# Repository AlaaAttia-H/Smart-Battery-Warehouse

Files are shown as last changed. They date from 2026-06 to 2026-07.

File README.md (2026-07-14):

# Smart Battery Warehouse Monitoring and Response System

## Overview

This project implements a Smart Battery Warehouse Monitoring and Response System using:

```text
IoT sensing
MQTT communication
AI planning
automatic actuator control
dashboard visualisation
manager notifications
```

The system monitors:

```text
temperature
humidity
gas_status
occupancy
battery_status
```

The system controls:

```text
fan
buzzer
RGB LED
shutter/servo
manager notifications
dashboard updates
```

## Main System Structure

```text
Smart-Battery-Warehouse/
├── README.md
├── laptop/
│   ├── README.md
│   └── src/
├── raspberry-pi/
│   ├── README.md
│   └── src/
├── dashboard/
│   ├── README.md
│   └── flows.json
└── docs/component README files
```

## Where to Find Setup Instructions

This root README gives only the general overview.  
For detailed setup and running instructions, use the README file inside each component folder.

### Raspberry Pi Setup

Use:

```text
raspberry-pi/README.md
```

This explains:

```text
Raspberry Pi connection
Mosquitto setup
pigpio setup
copying Raspberry Pi files
running the hardware node
battery input
Grove button occupancy
I2C troubleshooting
manual MQTT tests
```

### Laptop Controller Setup

Use:

```text
laptop/README.md
```

This explains:

```text
Python virtual environment
MQTT broker IP configuration
running the laptop AI controller
context signature
replanning logic
```

### AI Planner Setup

Use:

```text
laptop/src/planner/README.md
```

This explains:

```text
Fast Downward download and setup
PDDL domain and problem files
problem_generator.py logic
planner testing
HIGH/MEDIUM/LOW planning rules
shutter planning based on occupancy
```

### Executor Explanation

Use:

```text
laptop/src/executor/README.md
```

This explains:

```text
how planner actions are executed
how MQTT commands are published
why the executor stays generic
```

### Knowledge Base Explanation

Use:

```text
laptop/src/knowledge_base/README.md
```

This explains:

```text
planner action to MQTT mappings
warehouse zones
notification meanings
threshold access
```

### MQTT Topics

Use:

```text
laptop/src/mqtt/README.md
```

or the MQTT README in the project docs, depending on the final folder structure.

This explains:

```text
sensor topics
context topics
planning topics
notification topics
actuator command topics
example payloads
```

### Notifications Setup

Use:

```text
laptop/src/notifications/README.md
```

This explains:

```text
ntfy setup
notification topic
notification testing
notification action meanings
```

### Dashboard Setup

Use:

```text
dashboard/README.md
```

This explains:

```text
Node-RED setup
Dashboard 2 installation
importing flows.json
dashboard MQTT topics
opening the dashboard page
```

## Main Component Responsibilities

### Raspberry Pi

```text
runs Mosquitto MQTT broker
runs the hardware node
reads DHT temperature/humidity
reads MQ2 gas status
reads Grove button occupancy
reads battery value from JSON input
controls fan, buzzer, RGB LED, and shutter/servo
runs Node-RED dashboard server
```

### Laptop

```text
receives sensor values through MQTT
calculates risk level and battery condition
generates PDDL problem files
runs Fast Downward
executes planner actions through MQTT
sends ntfy notifications
publishes dashboard context and plan topics
```

### Dashboard

```text
subscribes to MQTT topics
shows live sensor values
shows risk level and system state
shows current and previous AI plans
shows notifications and actuator states
```

## Final Behaviour Summary

### Normal

```text
risk_level = LOW
LED = GREEN
fan = OFF
buzzer = OFF
shutter = OPEN
```

### Medium Risk

```text
risk_level = MEDIUM
LED = ORANGE
fan = ON
buzzer = OFF
shutter = OPEN
```

### High Risk With Occupancy

```text
risk_level = HIGH
occupancy = 1
LED = RED
buzzer gives two short beeps
manager receives high-risk notification
evacuation notification is sent
shutter stays open
```

### High Risk Without Occupancy

```text
risk_level = HIGH
occupancy = 0
LED = RED
buzzer gives two short beeps
manager receives high-risk notification
shutter closes
```

### Battery Low

```text
battery_condition = LOW
manager receives battery warning notification
```

### Battery Critical

```text
battery_condition = CRITICAL
manager receives battery maintenance notification
```

## Full Run Order

For full detailed commands, see the component README files.

General order:

```text
1. Start Mosquitto on Raspberry Pi.
2. Start Node-RED dashboard on Raspberry Pi.
3. Start Raspberry Pi hardware node.
4. Start battery input if needed.
5. Start laptop AI controller.
6. Open dashboard.
7. Test demo scenarios.
```

## Important Notes

```text
Mosquitto broker runs on Raspberry Pi.
Raspberry Pi hardware node runs on Raspberry Pi.
Node-RED dashboard runs on Raspberry Pi.
Fast Downward runs on the laptop.
Laptop AI controller runs on the laptop.
The executor stays generic and only publishes mapped MQTT actions.
The Raspberry Pi only executes received actuator commands.
The planner/problem generator decides which actions are needed.
```

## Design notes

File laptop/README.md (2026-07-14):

# Laptop Controller Setup

This README explains how to set up and run the laptop side of the project.

The laptop runs:

```text
MQTT laptop controller
context processor
PDDL problem generator
Fast Downward planner
plan executor
notification manager
```

## 1. Open the Project Folder

Open the project root in VS Code or PowerShell:

```powershell
cd "<PATH_TO_PROJECT>/Smart-Battery-Warehouse"
```

Example:

```powershell
cd "C:\Users\<YOUR_USERNAME>\Documents\Smart-Battery-Warehouse"
```

## 2. Create Virtual Environment

```powershell
python -m venv venv
```

Activate it:

```powershell
.\venv\Scripts\activate
```

## 3. Install Required Packages

```powershell
python -m pip install --upgrade pip
python -m pip install paho-mqtt requests
```

## 4. Configure Raspberry Pi Broker IP

Edit:

```text
config/config.json
```

Set the Raspberry Pi IP:

```json
"mqtt": {
  "broker_host": "<RASPBERRY_PI_IP>",
  "broker_port": 1883
}
```

Example:

```json
"mqtt": {
  "broker_host": "192.168.137.70",
  "broker_port": 1883
}
```

## 5. Run the Laptop Controller

From the project root:

```powershell
.\venv\Scripts\activate
python laptop/src/main.py
```

The controller will:

```text
subscribe to sensor topics
calculate risk level and battery condition
publish context topics
generate PDDL problem
run planner
publish current and last plans
execute MQTT actuator commands
send notifications
```

## 6. Important

Run the controller from the project root.

Use:

```powershell
python laptop/src/main.py
```

Do not run package files directly like:

```powershell
python mqtt/laptop_controller.py
```

because that can cause import errors.

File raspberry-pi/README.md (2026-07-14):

# Raspberry Pi Setup and Run Guide

This README explains the Raspberry Pi side of the Smart Battery Warehouse project.

The Raspberry Pi is responsible for:

```text
running the Mosquitto MQTT broker
running the Raspberry Pi hardware node
publishing sensor values
reading the Grove button for occupancy
reading battery status from a JSON input file
receiving actuator commands
controlling the fan, buzzer, RGB LED, and shutter/servo
running the Node-RED dashboard server
```

## 1. Hardware and Pi Information

```text
Model: Raspberry Pi Model B+
OS: Raspberry Pi OS Lite 32-bit
Hostname: SCIOT
Username: group29
Password: SCIOT29-group
```

## 2. Project Structure on the Raspberry Pi

The code should be copied to:

```text
/home/group29/sciot_project/
```

Expected structure:

```text
sciot_project/
├── main.py
├── battery_simulator.py
├── runtime/
│   └── battery_state.json
├── hardware/
│   ├── grove_inputs.py
│   ├── grove_outputs.py
│   └── pi_direct.py
└── mqtt/
    ├── rpi_hardware_node.py
    └── topics.py
```

## 3. Connect to the Raspberry Pi

From Windows PowerShell:

```powershell
ssh group29@SCIOT.local
```

or:

```powershell
ssh group29@<RASPBERRY_PI_IP>
```

To check the Raspberry Pi IP after logging in:

```bash
hostname -I
```

## 4. Install and Start Mosquitto

Mosquitto is the MQTT broker. It runs on the Raspberry Pi.

Check if Mosquitto is running:

sudo systemctl status mosquitto

Start Mosquitto:

```bash
sudo systemctl start mosquitto
```

Enable Mosquitto on boot:

```bash
sudo systemctl enable mosquitto
```

Check status:

```bash
sudo systemctl status mosquitto
```

Check that port `1883` is open:

```bash
sudo ss -ltnp | grep 1883
```
Install Mosquitto if needed:

```bash
sudo apt update
sudo apt install mosquitto mosquitto-clients -y
```

## 5. Allow Laptop Connections to Mosquitto

If the laptop controller cannot connect to the broker, create or edit:

```bash
sudo nano /etc/mosquitto/conf.d/sciot.conf
```

Add:

```text
listener 1883
allow_anonymous true
```

Restart Mosquitto:

```bash
sudo systemctl restart mosquitto
```

## 6. Create Project Folder on Raspberry Pi

```bash
mkdir -p ~/sciot_project
mkdir -p ~/sciot_project/mqtt
mkdir -p ~/sciot_project/hardware
mkdir -p ~/sciot_project/runtime
```

## 7. Create and Activate Virtual Environment

```bash
cd ~/sciot_project
python3 -m venv venv
source venv/bin/activate
```

Install required Python packages:

```bash
pip install paho-mqtt
```

If needed, also install the hardware libraries used by the Pi code:

```bash
pip install smbus2 pigpio
```

## 8. Enable pigpio

The servo, MQ2 sensor, and RGB LED use direct Raspberry Pi GPIO through `pigpio`.

Check status:

```bash
sudo systemctl status pigpiod
```

Start pigpio:

```bash
sudo systemctl start pigpiod
```

Enable on boot:

```bash
sudo systemctl enable pigpiod
```

## 9. Copy Raspberry Pi Code from Laptop to Pi

From Windows PowerShell, run these commands from the main project root:

```powershell
scp -r .\raspberry-pi\src\ group29@<RASPBERRY_PI_IP>:/home/group29/sciot_project/
```

Example:

```powershell
scp .\raspberry-pi\src\main.py group29@192.168.137.70:/home/group29/sciot_project/main.py
```

## 10. Run the Raspberry Pi Hardware Node

On the Raspberry Pi:

```bash
cd ~/sciot_project
source venv/bin/activate
python main.py
```

The hardware node publishes:

```text
warehouse/sensors/temperature
warehouse/sensors/humidity
warehouse/sensors/gas_status
warehouse/sensors/occupancy
warehouse/sensors/battery_status
```

The hardware node subscribes to:

```text
warehouse/actuators/fan/command
warehouse/actuators/buzzer/command
warehouse/actuators/led/command
warehouse/actuators/shutter/command
```

## 11. Run Battery Input

Battery status is entered manually because the project does not use a real battery sensor.

Open another Raspberry Pi terminal:

```bash
cd ~/sciot_project
source venv/bin/activate
python battery_input.py
```

Example values:

```text
90 -> normal battery
40 -> low battery
10 -> critical battery
```

The value is written to:

```text
runtime/battery_state.json
```

The Raspberry Pi hardware node reads this file and publishes the value to:

```text
warehouse/sensors/battery_status
```

## 12. Occupancy Input

Occupancy is controlled using the real Grove button.

```text
button press toggles occupancy between 0 and 1
```

The Raspberry Pi publishes the current occupancy to:

```text
warehouse/sensors/occupancy
```

There is no separate `occupancy_input.py` script in the final hardware version because occupancy comes from the real button.

## 13. Hardware Behaviour

### DHT Sensor

The DHT sensor provides:

```text
temperature
humidity
```

These are published to:

```text
warehouse/sensors/temperature
warehouse/sensors/humidity
```

### MQ2 Gas Sensor

The MQ2 sensor publishes:

```text
OK
ALERT
```

to:

```text
warehouse/sensors/gas_status
```

### Fan

The fan receives MQTT commands on:

```text
warehouse/actuators/fan/command
```

Example payloads:

```text
OFF
ON
40
70
```

### Buzzer

The buzzer receives commands on:

```text
warehouse/actuators/buzzer/command
```

For an `ON` command, the buzzer gives two short beeps and then turns off automatically.

### RGB LED

The RGB LED receives commands on:

```text
warehouse/actuators/led/command
```

Example payloads:

```text
GREEN
ORANGE
RED
OFF
```

### Shutter / Servo

The shutter servo receives commands on:

```text
warehouse/actuators/shutter/command
```

Example payloads:

```text
OPEN
CLOSE
HALF
```

The Raspberry Pi only executes the command it receives. The decision about whether the shutter should close is made by the laptop AI planner/problem generator.

## 14. Start Node-RED Dashboard

Node-RED runs on the Raspberry Pi.

Start Node-RED:

```bash
node-red-start
```

Open the Node-RED editor from the laptop browser:

```text
http://<RASPBERRY_PI_IP>:1880
```

Open the dashboard:

```text
http://<RASPBERRY_PI_IP>:1880/dashboard
```

Because Node-RED and Mosquitto both run on the Raspberry Pi, MQTT nodes in Node-RED should use:

```text
host: localhost
port: 1883
```

## 15. Full Raspberry Pi Run Order

### Terminal 1

```bash
sudo systemctl start mosquitto
node-red-start
```

### Terminal 2

```bash
cd ~/sciot_project
source venv/bin/activate
python main.py
```

### Terminal 3, optional battery input

```bash
cd ~/sciot_project
source venv/bin/activate
python battery_input.py
```

## 16. Manual MQTT Testing

Subscribe to all warehouse topics:

```bash
mosquitto_sub -h localhost -t "warehouse/#" -v
```

Test LED command:

```bash
mosquitto_pub -h localhost -t "warehouse/actuators/led/command" -m "GREEN"
```

Test buzzer command:

```bash
mosquitto_pub -h localhost -t "warehouse/actuators/buzzer/command" -m "ON"
```

Test shutter command:

```bash
mosquitto_pub -h localhost -t "warehouse/actuators/shutter/command" -m "OPEN"
```

## 17. Troubleshooting

### Laptop cannot connect to broker

Check the Pi IP:

```bash
hostname -I
```

Check Mosquitto:

```bash
sudo systemctl status mosquitto
```

Restart Mosquitto:

```bash
sudo systemctl restart mosquitto
```

Check port:

```bash
sudo ss -ltnp | grep 1883
```

### pigpio error

If the servo, MQ2, or RGB LED gives a pigpio connection error:

```bash
sudo systemctl start pigpiod
```

Then run the node again:

```bash
python main.py
```

### I2C / GrovePi error

If this appears:

```text
OSError: [Errno 5] Input/output error
```

Stop the running script:

```bash
sudo pkill -f main.py
```

Then physically:

```text
remove the Grove module/cable
plug it back in firmly
```

If needed, reboot:

```bash
sudo reboot
```

Then run again:

```bash
cd ~/sciot_project
source venv/bin/activate
python main.py
```

### Dashboard shows no values

Check:

```text
Mosquitto is running
Node-RED is running
Raspberry Pi hardware node is running
Node-RED MQTT broker is set to localhost:1883
dashboard topics match the project MQTT topics
```

## 18. Notes

```text
The Raspberry Pi is the MQTT broker host.
The laptop connects to the Raspberry Pi IP.
The Raspberry Pi hardware node uses localhost as the broker address.
Battery is manual/software input.
Occupancy uses the real Grove button.
The shutter decision is made by the laptop planner.
The Raspberry Pi only executes received actuator commands.
```

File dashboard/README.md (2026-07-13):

# SCIoT Dashboard - Node-RED

## Overview

This dashboard provides a real-time web interface for the Smart Battery Warehouse monitoring system. It is built with **Node-RED** and the **`@flowfuse/node-red-dashboard`** module (Dashboard 2), and communicates with the rest of the system through an **MQTT** broker (Mosquitto).

The dashboard displays:

- Current system state (NORMAL / WARNING / EMERGENCY)
- Live sensor readings (temperature, humidity, CO2 status)
- Historical charts (temperature and humidity over time)
- Actuator states (fan speed, buzzer, fire isolation shutter/servo)
- Notifications and evacuation alerts
- AI-generated action plan and plan history

## Architecture

```
main.py (Python backend)
   |
   |  publishes/subscribes
   v
Mosquitto (MQTT broker, localhost:1883)
   |
   |  mqtt in / mqtt out nodes
   v
Node-RED flow ("Flux 2")
   |
   |  ui-* nodes
   v
Dashboard 2 UI (http://<PI_IP>:1880/dashboard)
```

## Prerequisites

- Raspberry Pi with Raspberry Pi OS
- Node.js and npm
- Node-RED
- Mosquitto MQTT broker

## Installation

### 1. Install Mosquitto (MQTT broker)

```bash
sudo apt update
sudo apt install -y mosquitto mosquitto-clients
sudo systemctl enable mosquitto
sudo systemctl start mosquitto
```

Check that the broker is listening on port `1883`:

```bash
sudo systemctl status mosquitto
mosquitto_sub -h localhost -t '#' -v
```

### 2. Install Node-RED (if not already installed)

```bash
bash <(curl -sL https://raw.githubusercontent.com/node-red/linux-installers/master/deb/update-nodejs-and-nodered)
```

### 3. Install the Dashboard 2 module

```bash
cd ~/.node-red
npm install @flowfuse/node-red-dashboard
```

Alternatively, from the Node-RED editor: **Menu > Manage palette > Install**, then search for `@flowfuse/node-red-dashboard` and click **Install**.

### 4. Restart Node-RED

```bash
node-red-stop
node-red-start
# or, if managed by systemd:
sudo systemctl restart nodered
```

### 5. Import the dashboard flow

1. Open the Node-RED editor: `http://<PI_IP>:1880`
2. **Menu > Import**
3. Paste the flow JSON (tab "Flux 2")
4. Click **Import**, then **Deploy**

### 6. Access the dashboard

```
http://<PI_IP>:1880/dashboard
```

## MQTT Topics

| Topic | Direction | Payload | Retain |
|---|---|---|---|
| `warehouse/sensors/temperature` | publish | float (deg C) | no |
| `warehouse/sensors/humidity` | publish | float (%) | no |
| `warehouse/sensors/co2` | publish | 0 or 1 | no |
| `warehouse/context/system_state` | publish | `NORMAL` \| `WARNING` \| `EMERGENCY` | yes |
| `warehouse/context/latest_plan` | publish | string (action plan) | yes |
| `warehouse/actuators/fan` | publish | int (0-100, percent) | no |
| `warehouse/actuators/buzzer` | publish | `ON` \| `OFF` | no |
| `warehouse/actuators/servo` | publish | `OPEN` \| `CLOSED` | no |

## Running the Full System

```bash
# Terminal 1: Node-RED (dashboard and broker already running as services)
node-red-start

# Terminal 2: Python backend (real sensors/actuators)
python3 main.py
```

## Known Issues and Adjustments Needed

- **Simulator vs real hardware**: the flow includes simulator groups ("Simulator - Sensors" and "Simulator - System State") that auto-publish test data every 5-15 seconds. These must be disabled once `main.py` starts publishing real sensor/actuator data on the same topics, otherwise the two sources will conflict.
- **Debug node**: the `debug 1` node is active by default. Disable it in normal operation to reduce overhead in the sidebar.
- **Retained messages**: actuator topics (`fan`, `buzzer`, `servo`) are not currently retained, so dashboard widgets will appear empty after a page refresh until a new message is published. Consider setting `retain: true` on these topics.
- **CO2 payload format**: the simulator publishes a binary flag (0 or 1) on the CO2 topic. Confirm that the real MQ-2 sensor code (`pi_direct.py`) publishes in the same format, since the "CO2 Classifier" node expects a value where `>= 1` means HIGH.
- **Broker security**: Mosquitto is currently configured without authentication or TLS. This is acceptable for local/lab use, but add a username and password (`mosquitto_passwd`) and enable TLS if the Pi will be reachable from a wider network.
- **Startup order**: Mosquitto must be running before Node-RED and `main.py` start, otherwise MQTT connections will fail.
- **Dashboard control**: the current flow is read-only (sensor/state display). There is no UI control (button, switch) wired to an `mqtt out` node to manually override actuators from the dashboard.

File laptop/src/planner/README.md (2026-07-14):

# Planner README

The planner uses PDDL and Fast Downward.

## Folder

```text
laptop/src/planner/
├── README.md
├── ai_planner.py
├── domain.pddl
├── problem_generator.py
└── generated_problem.pddl
```

## Fast Downward Setup

Official Fast Downward links:

```text
Main website:
https://www.fast-downward.org/

Latest releases / download:
https://www.fast-downward.org/latest/releases/

Quick start documentation:
https://www.fast-downward.org/latest/documentation/quick-start/

Windows installation guide:
https://www.fast-downward.org/latest/for-developers/blog/install-on-windows/
```

Download the latest release from the official releases page and extract it to any folder on the laptop.

Example folder:

```text
C:/tools/fast-downward/
```

The important file is:

```text
fast-downward.py
```

Build it from Developer PowerShell or x64 Native Tools Command Prompt:

```powershell
cd "<PATH_TO_FAST_DOWNWARD_FOLDER>"
py build.py
py fast-downward.py --help
```

Then set the path in:

```text
laptop/src/config/config.json
```

```json
"fast_downward_path": "<PATH_TO_FAST_DOWNWARD_FOLDER>/fast-downward.py"
```

Use forward slashes `/` in the JSON path. Do not commit a personal machine-specific path if the repository is shared.

## Planner Responsibility

The planner decides what actions are needed.

The executor should not contain special rules like:

```text
waiting for occupancy
checking sensors directly
dashboard formatting
hardware-specific safety logic
```

## High Risk Rule

```text
HIGH risk + occupancy = 1:
activate-alarm
set-red-light
notify-manager
request-evacuation
update-dashboard
do not close shutter

HIGH risk + occupancy = 0:
activate-alarm
set-red-light
notify-manager
close-shutter
update-dashboard
```

## Fan Rule

```text
MEDIUM risk -> start-fan
HIGH risk -> do not start fan
LOW risk -> stop-fan
```

## Battery Rule

```text
LOW battery -> send-battery-warning
CRITICAL battery -> request-battery-maintenance
```

## Test

From `laptop/src`:

```powershell
python -m planner.problem_generator
python -m planner.ai_planner
```

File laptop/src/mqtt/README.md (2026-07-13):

# MQTT Topics

This README lists the MQTT topics used in the project.

## Sensor Topics

Published by Raspberry Pi:

```text
warehouse/sensors/temperature
warehouse/sensors/humidity
warehouse/sensors/gas_status
warehouse/sensors/occupancy
warehouse/sensors/battery_status
```

## Context Topics

Published by laptop controller:

```text
warehouse/context/risk_level
warehouse/context/system_state
warehouse/context/battery_condition
```

## Planning Topics

Published by laptop controller:

```text
warehouse/planning/plan
warehouse/planning/current_plan
warehouse/planning/last_plan
warehouse/planning/execution_status
```

## Notification Topic

```text
warehouse/notifications/manager
```

## Actuator Command Topics

Published by laptop controller and subscribed to by Raspberry Pi:

```text
warehouse/actuators/fan/command
warehouse/actuators/buzzer/command
warehouse/actuators/led/command
warehouse/actuators/shutter/command
```

## Example Payloads

```text
warehouse/sensors/gas_status -> OK / ALERT
warehouse/sensors/occupancy -> 0 / 1
warehouse/context/risk_level -> LOW / MEDIUM / HIGH
warehouse/context/system_state -> NORMAL / WARNING / EMERGENCY
warehouse/context/battery_condition -> NORMAL / LOW / CRITICAL
warehouse/actuators/fan/command -> OFF / 40 / ON
warehouse/actuators/buzzer/command -> ON / OFF
warehouse/actuators/led/command -> GREEN / ORANGE / RED / OFF
warehouse/actuators/shutter/command -> OPEN / CLOSE
```

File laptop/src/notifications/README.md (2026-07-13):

# NTFY App Setup

Follow the steps below to receive notifications from this project.

## 1. Install the ntfy App

Download and install the **ntfy** app on your device:

- **Android:** Google Play Store
- **iOS:** Apple App Store

## 2. Subscribe to the Topic

1. Open the **ntfy** app.
2. Tap the **+** button to add a new subscription.
3. Enter the following topic:

   ```
   smartwarehouse-group29-alerts
   ```

4. Tap **Subscribe**.

## 3. Enable Notifications

Allow the app to send notifications when prompted. If notifications are disabled, enable them in your device's notification settings.

## 4. You're Ready!

You will now receive all notifications sent to the following topic:

`smartwarehouse-group29-alerts`

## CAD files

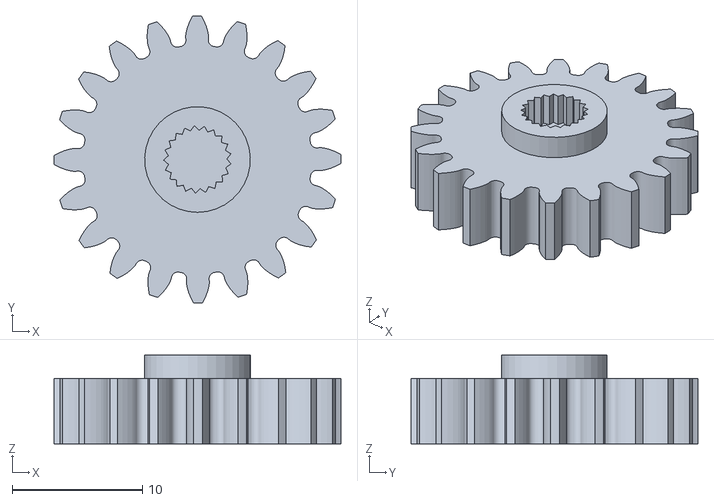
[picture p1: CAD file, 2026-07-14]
hardware/Model/obj_2_Body1.stl
22.0 x 22.0 x 6.80

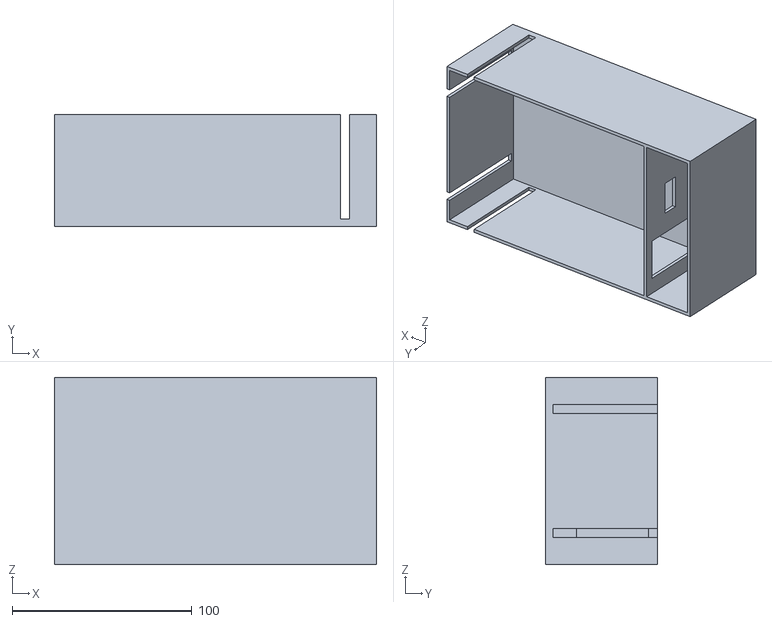
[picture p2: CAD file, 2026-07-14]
hardware/Model/Warehouse.STL
179.0 x 62.0 x 104.0

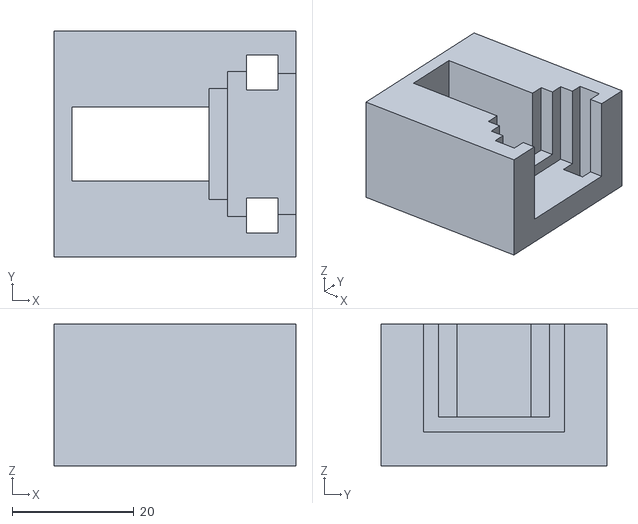
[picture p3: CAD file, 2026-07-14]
hardware/Model/obj_1_Body1.stl
39.8 x 37.2 x 23.3

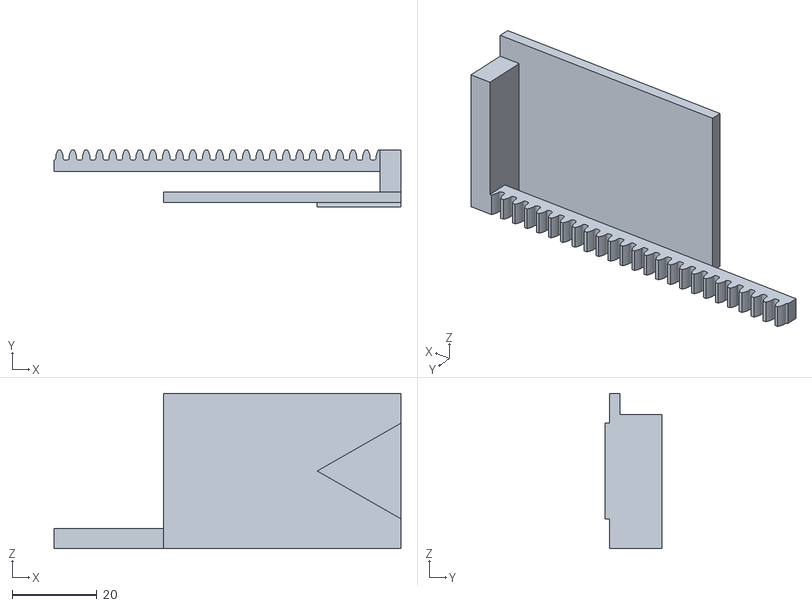
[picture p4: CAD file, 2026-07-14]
hardware/Model/obj_3_Body1.stl
81.7 x 13.3 x 36.6

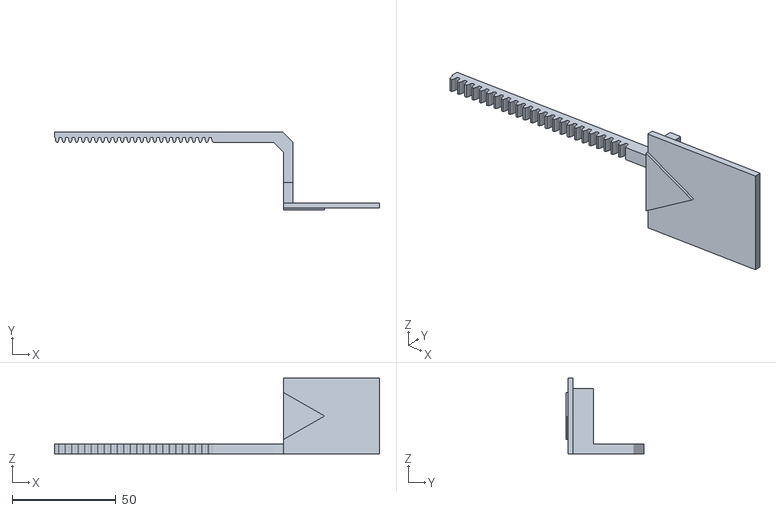
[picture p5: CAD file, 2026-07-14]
hardware/Model/obj_4_Body1.stl
156.8 x 37.7 x 36.6

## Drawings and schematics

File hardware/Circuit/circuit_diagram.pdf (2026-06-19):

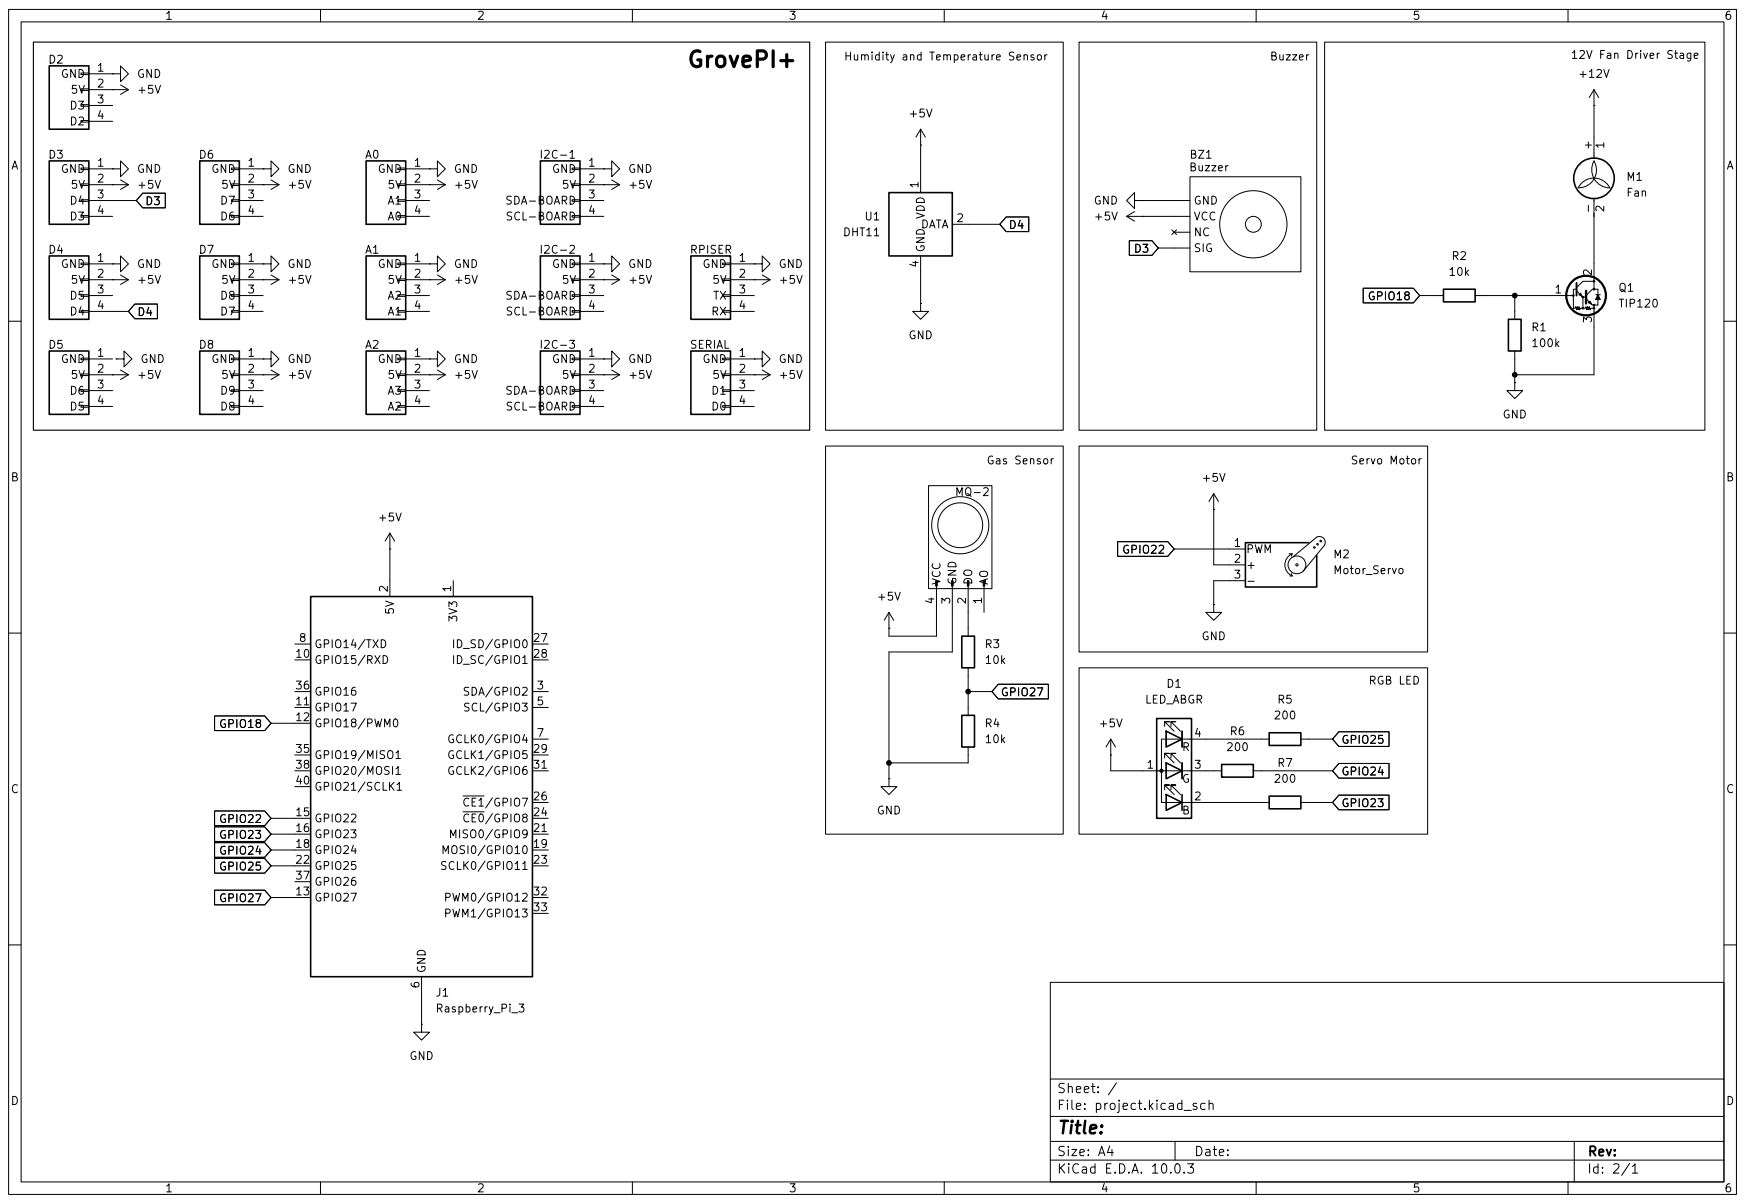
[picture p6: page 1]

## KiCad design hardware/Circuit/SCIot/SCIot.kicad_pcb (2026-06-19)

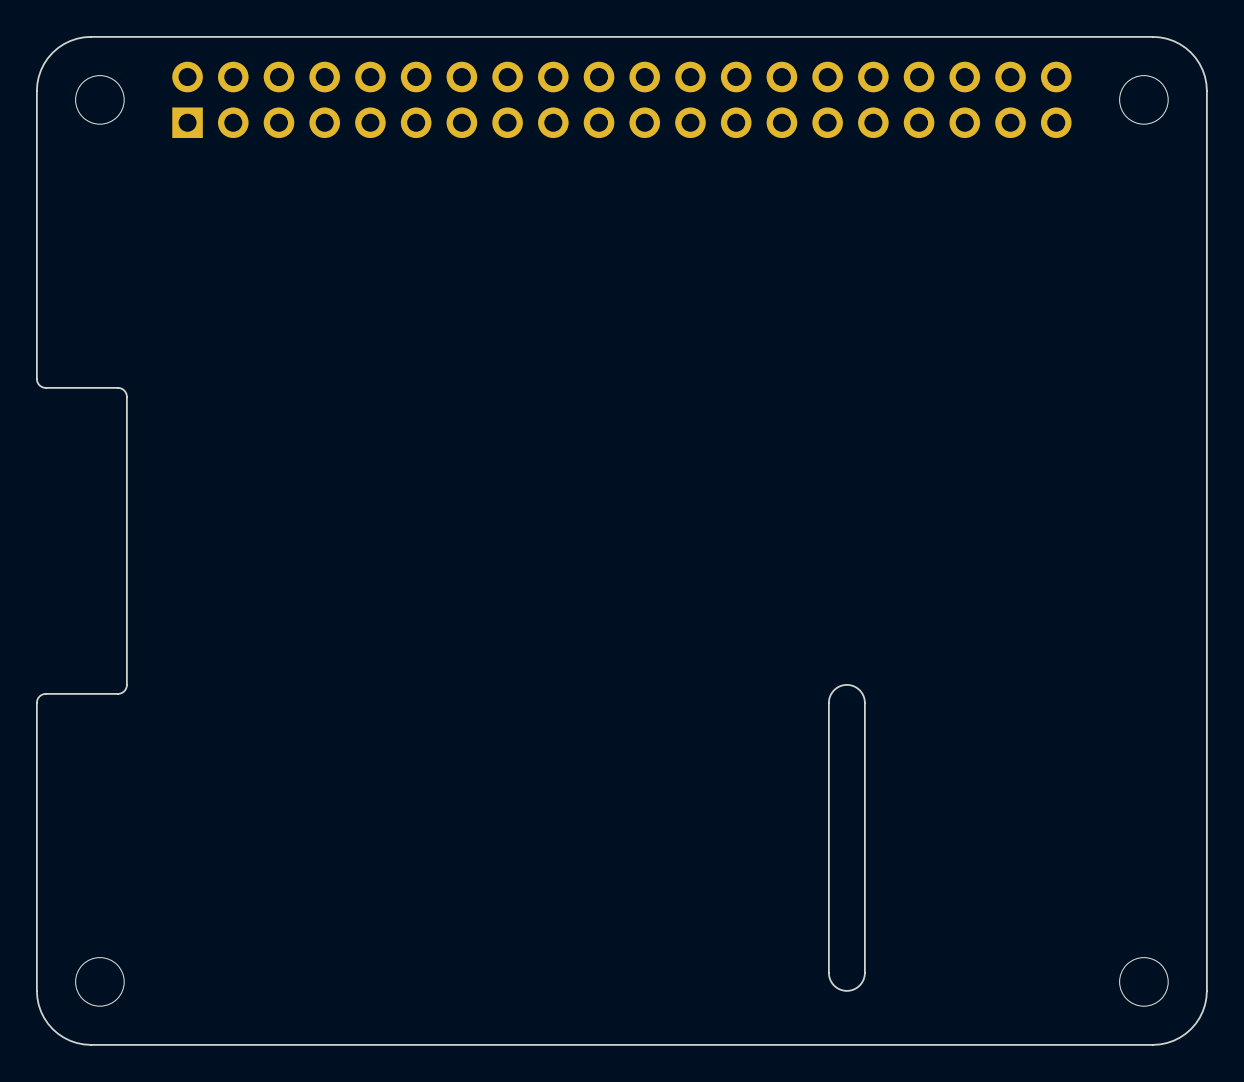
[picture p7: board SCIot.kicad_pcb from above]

Board: 2 copper layers, 65.0 x 56.0 mm, 5 parts (1 on the bottom side), 3 nets, no tracks yet.

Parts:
J1: GPIO; PinSocket_2x20_P2.54mm_Vertical
MH1, MH2, MH3, MH4: MountingHole_2.7mm_M2.5

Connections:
+3V3: J1.1, J1.17
+5V: J1.2, J1.4
GND: J1.6, J1.9, J1.14, J1.20, J1.25, J1.30, J1.34, J1.39

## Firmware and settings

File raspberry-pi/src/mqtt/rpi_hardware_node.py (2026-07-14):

"""
Raspberry Pi MQTT hardware node.
"""

import json
import time
from pathlib import Path

import paho.mqtt.client as mqtt

from hardware.grove_inputs import pin_mode, read_button, read_dht
from hardware.grove_outputs import GroveBuzzer
from hardware.pi_direct import DCFan, MQ2Sensor, RGBLed, Servo

from mqtt.topics import (
    ACTUATOR_BUZZER_COMMAND,
    ACTUATOR_COMMAND_TOPICS,
    ACTUATOR_FAN_COMMAND,
    ACTUATOR_LED_COMMAND,
    ACTUATOR_SHUTTER_COMMAND,
    SENSOR_BATTERY_STATUS,
    SENSOR_GAS_STATUS,
    SENSOR_HUMIDITY,
    SENSOR_OCCUPANCY,
    SENSOR_TEMPERATURE,
)


# GrovePi configuration
DHT_PIN = 4
DHT_TYPE = 0

BUZZER_PIN = 3

BUTTON_PIN = 8
BUTTON_DEBOUNCE_SECONDS = 0.3
BUTTON_ACTIVE_LOW = False

# Direct Raspberry Pi GPIO configuration
SERVO_PIN = 22
SERVO_OPEN_ANGLE = 90
SERVO_CLOSE_ANGLE = 20
SERVO_HALF_ANGLE = 45

SERVO_STEP = 2
SERVO_STEP_DELAY = 0.03
MQ2_PIN = 27

LED_R_PIN = 25
LED_G_PIN = 24
LED_B_PIN = 23

# Battery input file
PROJECT_ROOT = Path(__file__).resolve().parents[1]
BATTERY_STATE_FILE = PROJECT_ROOT / "runtime" / "battery_state.json"
DEFAULT_BATTERY_STATUS = 100


class RaspberryPiHardwareNode:
    def __init__(self, broker="localhost", port=1883, read_interval=2.0):
        self.broker = broker
        self.port = port
        self.read_interval = read_interval

        self.bus = None
        self.client = None

        self.fan = None
        self.servo = None
        self.current_servo_angle = SERVO_OPEN_ANGLE
        self.mq2 = None
        self.led = None
        self.buzzer = None

        self.occupancy = 0
        self.last_button_state = None
        self.last_button_toggle_time = 0

    def open_bus(self):
        import smbus2

        bus = smbus2.SMBus(1)
        time.sleep(1)
        return bus

    def setup_button(self):
        try:
            pin_mode(self.bus, BUTTON_PIN, 0)
            print(f"[BUTTON] Initialised on Grove D{BUTTON_PIN}")

        except OSError as e:
            print(f"[BUTTON WARNING] Button setup failed: {e}")
            print("[BUTTON WARNING] Continuing. Button reads may fail until I2C recovers.")

    def setup_hardware(self):
        print("[SYSTEM] Initialising hardware...")

        self.bus = self.open_bus()

        self.setup_button()

        self.fan = DCFan()
        self.servo = Servo(gpio_pin=SERVO_PIN)
        self.mq2 = MQ2Sensor(gpio_pin=MQ2_PIN)
        self.led = RGBLed(pin_r=LED_R_PIN, pin_g=LED_G_PIN, pin_b=LED_B_PIN)

        self.buzzer = GroveBuzzer(pin=BUZZER_PIN)
        self.buzzer.update_bus(self.bus)

        self.fan.set_speed(0)
        self.move_servo_slowly(SERVO_OPEN_ANGLE)
        self.led.set_color(0, 0, 0)
        self.buzzer.stop_siren()

        print("[SYSTEM] Hardware ready")

    def reopen_bus(self):
        print("[I2C] Reopening I2C bus...")

        try:
            if self.bus:
                self.bus.close()
        except Exception as e:
            print(f"[I2C WARNING] Could not close bus: {e}")

        time.sleep(2)

        self.bus = self.open_bus()
        time.sleep(1)

        try:
            pin_mode(self.bus, BUTTON_PIN, 0)
            print("[I2C] Button reconfigured")
        except OSError as e:
            print(f"[BUTTON WARNING] Could not reconfigure button: {e}")

        if self.buzzer:
            self.buzzer.update_bus(self.bus)

        print("[I2C] Bus reopened")

    def setup_mqtt(self):
        print(f"[MQTT] Connecting to broker at {self.broker}:{self.port}")

        self.client = mqtt.Client(mqtt.CallbackAPIVersion.VERSION2)
        self.client.on_connect = self.on_connect
        self.client.on_message = self.on_message

        self.client.connect(self.broker, self.port, keepalive=60)
        self.client.loop_start()

    def on_connect(self, client, userdata, flags, reason_code, properties):
        print(f"[MQTT] Connected: {reason_code}")

        for topic in ACTUATOR_COMMAND_TOPICS:
            client.subscribe(topic)
            print(f"[MQTT] Subscribed to {topic}")

    def on_message(self, client, userdata, msg):
        topic = msg.topic
        message = msg.payload.decode(errors="replace").strip()

        print(f"[MQTT RECEIVED] {topic} -> {message}")

        try:
            if topic == ACTUATOR_FAN_COMMAND:
                self.handle_fan_command(message)

            elif topic == ACTUATOR_BUZZER_COMMAND:
                self.handle_buzzer_command(message)

            elif topic == ACTUATOR_LED_COMMAND:
                self.handle_led_command(message)

            elif topic == ACTUATOR_SHUTTER_COMMAND:
                self.handle_shutter_command(message)

        except Exception as e:
            print(f"[MQTT ERROR] Could not handle command: {e}")

    def publish(self, topic, value):
        if self.client:
            self.client.publish(topic, str(value))

    def handle_fan_command(self, command):
        command = command.upper()
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

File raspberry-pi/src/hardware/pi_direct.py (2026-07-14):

import os
import time
import pigpio

PWM_PATH = "/sys/class/pwm/pwmchip0"
PWM_CHANNEL = "0"
PWM_PERIOD_NS = 20_000_000


class DCFan:
    """DC fan control via PWM on GPIO18"""

    def __init__(self, period_ns: int = PWM_PERIOD_NS):
        self.period_ns = period_ns
        self._pwm_path = f"{PWM_PATH}/pwm{PWM_CHANNEL}"
        self._running = False
        self._init()

    def _init(self):
        self._unexport_if_exists()
        self._export()
        self._write("period", self.period_ns)
        self._write("duty_cycle", 0)
        self._write("enable", 1)
        self._running = True
        print("[FAN] Initialized")

    def set_speed(self, percent: float):
        """Set fan speed (0-100%)"""
        percent = max(0.0, min(100.0, percent))
        self._write("duty_cycle", self._percent_to_ns(percent))
        print(f"[FAN] Speed {percent:.1f}%")

    def stop(self):
        """Stop fan and release PWM"""
        if self._running:
            self._write("duty_cycle", 0)
            self._write("enable", 0)
            self._unexport_if_exists()
            self._running = False
            print("[FAN] Stopped")

    def _export(self):
        with open(f"{PWM_PATH}/export", "w") as f:
            f.write(PWM_CHANNEL)
        time.sleep(0.1)

    def _unexport_if_exists(self):
        if os.path.exists(self._pwm_path):
            try:
                self._write("enable", 0)
            except OSError:
                pass
            with open(f"{PWM_PATH}/unexport", "w") as f:
                f.write(PWM_CHANNEL)
            time.sleep(0.1)

    def _write(self, attr: str, value):
        with open(f"{self._pwm_path}/{attr}", "w") as f:
            f.write(str(value))

    def _percent_to_ns(self, percent: float) -> int:
        return int(self.period_ns * percent / 100)

    def __enter__(self):
        return self

    def __exit__(self, *_):
        self.stop()


SERVO_MIN_PW = 500
SERVO_MAX_PW = 2500


class Servo:
    """Servo control via pigpio on GPIO22"""

    def __init__(self, gpio_pin: int, min_pw: int = SERVO_MIN_PW, max_pw: int = SERVO_MAX_PW):
        self.pin = gpio_pin
        self.min_pw = min_pw
        self.max_pw = max_pw

        self._pi = pigpio.pi()
        if not self._pi.connected:
            raise RuntimeError("[SERVO] Cannot connect to pigpiod. Start it with: sudo systemctl start pigpiod")
        print("[SERVO] Initialized")

    def set_position(self, angle: float):
        """Set servo position (0-180 degrees)"""
        angle = max(0.0, min(180.0, angle))
        pw = int(self.min_pw + (self.max_pw - self.min_pw) * angle / 180.0)
        self._pi.set_servo_pulsewidth(self.pin, pw)
        # print(f"[SERVO] Position {angle:.1f}°")

    def stop(self):
        self._pi.set_servo_pulsewidth(self.pin, 0)
        self._pi.stop()
        print("[SERVO] Stopped")

    def __enter__(self):
        return self

    def __exit__(self, *_):
        self.stop()

class MQ2Sensor:
    """MQ-2 gas sensor (binary output via GPIO27)"""

    def __init__(self, gpio_pin: int):
        self.pin = gpio_pin
        self._pi = pigpio.pi()

        if not self._pi.connected:
            raise RuntimeError("[MQ2] Cannot connect to pigpiod. Start it with: sudo systemctl start pigpiod")

        self._pi.set_mode(self.pin, pigpio.INPUT)
        self._pi.set_pull_up_down(self.pin, pigpio.PUD_UP)
        print("[MQ2] Initialized")

    def is_gas_detected(self) -> bool:
        """Returns True if gas detected (pin LOW)"""
        return self._pi.read(self.pin) == 0

    def stop(self):
        self._pi.stop()
        print("[MQ2] Stopped")

    def __enter__(self):
        return self

    def __exit__(self, *_):
        self.stop()

class RGBLed:
    """RGB LED control via pigpio (common anode)"""

    def __init__(self, pin_r: int, pin_g: int, pin_b: int):
        self.pin_r = pin_r
        self.pin_g = pin_g
        self.pin_b = pin_b

        self._pi = pigpio.pi()
        if not self._pi.connected:
            raise RuntimeError("[RGB] Cannot connect to pigpiod")

        self.set_color(0, 0, 0)
        print("[RGB] Initialized")

    def _set_channel(self, pin: int, value: int):
        if value == 0:
            self._pi.write(pin, 1)
        elif value == 255:
            self._pi.write(pin, 0)
        else:
            self._pi.set_PWM_dutycycle(pin, 255 - value)

    def set_color(self, r: int, g: int, b: int):
        r = max(0, min(255, int(r)))
        g = max(0, min(255, int(g)))
        b = max(0, min(255, int(b)))

        self._set_channel(self.pin_r, r)
        self._set_channel(self.pin_g, g)
        self._set_channel(self.pin_b, b)
        print(f"[LED] Color RGB({r},{g},{b})")

    def stop(self):
        self.set_color(0, 0, 0)
        self._pi.stop()
        print("[LED] Stopped")

    def __enter__(self):
        return self

    def __exit__(self, *_):
        self.stop()

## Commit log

2026-06-19 add KiCad project and circuit diagram
    [SCIot.kicad_pcb, SCIot.kicad_sch, project.kicad_sch]
2026-06-19 add raspberry pi code and docs

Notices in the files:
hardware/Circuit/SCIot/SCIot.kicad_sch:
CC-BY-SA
